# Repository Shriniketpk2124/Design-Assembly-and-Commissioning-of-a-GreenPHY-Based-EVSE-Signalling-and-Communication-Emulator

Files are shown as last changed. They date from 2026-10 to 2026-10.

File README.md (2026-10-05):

# Design, Assembly and Commissioning of a GreenPHY-Based EVSE Signalling and Communication Emulator

> **New here?** Start with [the software quickstart](docs/SOFTWARE_QUICKSTART.md) — two ways to fire up the JoSEV SECC (real hardware, or a two-container software simulation).

This repository documents an engineering prototype for EVSE-side control-pilot
(CP) signalling, HomePlug Green PHY communication and ISO 15118 message
observation with a real electric vehicle.

The project combines a custom mixed-signal PCB, an Arduino Nano, a Raspberry
Pi, a Devolo Green PHY modem and a hardware-adapted EcoG `iso15118` SECC.

> [!CAUTION]
> This is a laboratory communication emulator, not a charger. It has no
> authorized high-voltage DC source, verified insulation-monitoring system,
> pre-charge power stage or energy-transfer path. Never connect an HV/DC source
> or use this project to charge a vehicle.

## Demonstrated scope

The validated setup demonstrated:

- IEC 61851 CP generation and feedback monitoring;
- 1 kHz CP PWM, including the 5% HLC duty cycle;
- EV detection through the CP resistor states;
- EVSE-side SLAC using the `plc-utils` `evse` process;
- IPv6 link-local communication and SDP;
- ISO 15118-2 application-message exchange with external payment and no TLS;
- controlled termination before any physical energy transfer.

The final communication experiment used an explicitly enabled, protocol-only
PreCharge probe. It emulated the protocol status needed to pass CableCheck,
reached `PreChargeReq`, rejected the requested voltage/current command and
latched an external STOP. No DC output was produced.

## Repository layout

| Path | Contents |
| --- | --- |
| `hardware/kicad/PWM_Schematic/` | KiCad schematic, PCB, project-local symbols and footprints, and ERC/DRC reports |
| `hardware/bom/` | Bill of materials exported from the final schematic |
| `software/arduino/` | Arduino Nano CP controller and feedback-monitor firmware |
| `software/raspberry-pi/` | Raspberry Pi console, cockpit, test-day and evidence-collection tools |
| `software/josev-modifications/` | Hardware-controller additions for the EcoG ISO 15118 SECC |
| `software/configuration/` | Public configuration templates without local identifiers or secrets |
| `validation/procedures/` | Bench and real-EV validation procedures |
| `validation/selected-results/` | Sanitized results selected for publication |
| `thesis/` | Publication status only; the thesis report is not distributed here |

Raw packet captures, complete run folders, local environment files, vehicle
identifiers and PLC network keys are intentionally excluded.

## System overview

1. The Arduino generates the CP waveform and publishes comparator feedback over
   a serial connection.
2. The Raspberry Pi console is the sole owner of the Arduino serial connection
   and the two CP-path relay GPIOs.
3. The console writes an atomic state snapshot under `/run/evse-monday`.
4. The modified SECC reads that snapshot instead of controlling serial or GPIO
   hardware from inside the container.
5. The `plc-utils` `evse` process is the sole EVSE-side SLAC owner.
6. The Devolo modem carries HomePlug Green PHY traffic between the PCB coupling
   network and the vehicle.
7. The operations script records packet captures, application logs, controller
   state and checksums for each test attempt.

The word **Monday** remains in several tested script, class and configuration
names. It was the internal name of the final real-EV test workflow; it is not a
separate product or protocol.

## Hardware interface

The final KiCad PCB assigns the four-position vehicle-interface terminal as:

| Terminal | Net |
| --- | --- |
| `J2.1` | `EVSE_CP_OUT` |
| `J2.2` | `EVSE_PP_OUT` |
| `J2.3` | `ISO_GND` |
| `J2.4` | Not connected |

Verify these assignments against the supplied schematic and PCB before making
any physical connection. Wiring changes must be performed with all power
removed.

## Software provenance

The Josev modifications were developed against:

- upstream repository: `https://github.com/EcoG-io/iso15118.git`
- recorded base commit: `76bf85be572d16adbcd009a985d605622c3b7227`

The repository contains the project-specific additions and operational files,
not a claim of ownership over the upstream project. Retain all upstream license
and attribution notices when constructing a working tree.

## Replication order

This project is not a one-command charger build. A new user should proceed in
the following order:

1. Read this README and the safety limits.
2. Open `hardware/kicad/PWM_Schematic/PWM_Schematic.kicad_pro` and inspect the
   schematic, PCB, connector assignments and ERC/DRC reports.
3. Review the BOM and confirm every fitted component and polarity against the
   physical assembly.
4. Compile the Arduino sketch in `software/arduino/evse_cp_feedback_led/` for an
   Arduino Nano. The final sketch was verified with Arduino IDE and used 6102
   bytes of program storage and 448 bytes of global SRAM.
5. Prepare a Raspberry Pi with Docker Compose, Python 3, `tmux`, `tcpdump`,
   `plc-utils` and the required GPIO/serial permissions.
6. Follow the [Raspberry Pi installation and first-start guide](software/raspberry-pi/README.md)
   to check out the recorded upstream `iso15118` revision, prepare the local
   configuration and install the project additions.
7. Copy the public templates from `software/configuration/` to local,
   git-ignored configuration files and replace every `CHANGE_ME` value.
8. Run the hardware-independent tests and the operations-script preflight.
9. Validate State A, State B and 5% HLC feedback using bench loads before a
   vehicle is connected.
10. Only after the bench checks pass, follow the hardware-specific procedure in
    `validation/procedures/REAL_EV_COMMUNICATION_TEST_RUNBOOK.md`.

## Operating modes

`MONDAY_PRECHARGE_PROBE` materially changes the protocol boundary:

| Value | Behaviour |
| --- | --- |
| `0` | Default fail-safe mode. Reports `No_IMD`/`EVSE_NotReady` and requests STOP when CableCheck cannot be truthfully completed. |
| `1` | Test-only protocol probe. Emulates CableCheck readiness to observe entry into PreCharge, but still blocks the requested charging command and requests STOP. |

The probe does not add an IMD, contactor, pre-charge circuit or voltage source.
Do not enable it on a system containing an HV/DC energy path.

## Evidence and privacy

Complete test archives can contain MAC addresses, PLC network keys, EVCC
identifiers, hostnames, operator names and packet payloads. They are private
laboratory evidence and are not suitable for direct publication. Publish only
purpose-selected, sanitized extracts.

## Project status

The repository captures a thesis prototype and its validated laboratory
workflow. It is intended for research, review and reproducibility work by
qualified users. It is not production EVSE firmware and has not been certified
for charging, electrical safety or standards conformance.

The thesis report is withheld until publication permission is confirmed.

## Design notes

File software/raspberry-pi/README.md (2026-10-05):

# Raspberry Pi communication-controller workflow

This directory contains the host-side controller, test-day cockpit and evidence
collection tools used by the GreenPHY EVSE signalling and communication
emulator.

The historical name **Monday** is retained in filenames and runtime paths
because those names belong to the tested integration. It refers to the final
real-EV workflow, not to a protocol or separate software product.

> [!CAUTION]
> The software is for a communication-only laboratory rig. It must not control
> an HV/DC source or be treated as a production EVSE controller.

## Responsibilities

| Component | Responsibility |
| --- | --- |
| `evse_monday_console.py` | Sole owner of the Arduino serial connection and CP-path relay GPIOs |
| `monday_status.py` | Decodes and displays the current host state snapshot |
| `monday_ops.sh` | Preflight, service startup, cockpit, SLAC, capture, diagnosis, STOP, evidence collection and shutdown |
| `install_monday.sh` | Installs the project-specific files into a prepared upstream working tree |
| `verify_monday.sh` | Compatibility wrapper that invokes the final `monday_ops.sh preflight` checks |
| `tests/` | Hardware-independent parser, state and fail-safe tests |

The modified SECC does not open the Arduino serial port or directly control the
Pi GPIOs. It exchanges small JSON state/command files with the host under
`/run/evse-monday`.

## Installation and first startup

These instructions create a separate EcoG `iso15118` checkout and install the
project additions into it. They do not turn the prototype into a charger.
Keep the vehicle disconnected and keep every HV/DC source absent during the
installation and software checks.

The validated host was a Raspberry Pi 3B running a Debian-based Raspberry Pi
OS. The tested hardware names are fixed in the operational scripts:

- Green PHY interface: `eth0`;
- Arduino serial device: `/dev/ttyUSB0`;
- relay GPIOs: GPIO17 and GPIO27.

If the target uses different names or GPIOs, update and revalidate the scripts
before connecting a vehicle.

### 1. Install and verify host tools

On a Debian-based Raspberry Pi OS, install the ordinary command-line
dependencies with:

```bash
sudo apt update
sudo apt install -y \
  git make openssl python3 python3-serial \
  tmux tcpdump iproute2 util-linux coreutils psmisc default-jre
```

Install Docker Engine with the Docker Compose plugin using the instructions for
the installed Raspberry Pi OS release. Install Qualcomm Atheros `plc-utils`
and ensure that the Raspberry Pi `pinctrl` command is available. Package names
for Docker, `plc-utils` and `pinctrl` differ between OS releases, so verify the
result directly:

```bash
python3 --version
docker --version
sudo docker compose version
command -v tmux tcpdump ip ss script stdbuf sha256sum
command -v evse plctool plcstat pinctrl
```

Do not continue until every command returns successfully.

### 2. Clone this project and the recorded upstream revision

The project-specific Josev files were developed against EcoG `iso15118` commit
`76bf85be572d16adbcd009a985d605622c3b7227`. Use a separate checkout so another
simulation or development tree is not overwritten:

```bash
export PROJECT_CHECKOUT="$HOME/greenphy-evse-emulator"
export MONDAY_HOME="$HOME/thesis-monday-real-ev"
export MONDAY_REPO="$MONDAY_HOME/iso15118-real-ev"

git clone \
  https://github.com/Shriniketpk2124/Design-Assembly-and-Commissioning-of-a-GreenPHY-Based-EVSE-Signalling-and-Communication-Emulator.git \
  "$PROJECT_CHECKOUT"

mkdir -p "$MONDAY_HOME"
git clone https://github.com/EcoG-io/iso15118.git "$MONDAY_REPO"
git -C "$MONDAY_REPO" checkout --detach \
  76bf85be572d16adbcd009a985d605622c3b7227
git -C "$MONDAY_REPO" rev-parse HEAD
```

The final command must print the recorded commit exactly.

### 3. Build the SECC dependency image

The runtime Compose file expects an image named `iso15118-secc:latest`. Build
that image from the recorded upstream checkout:

```bash
cd "$MONDAY_REPO"
make generate_v2_certs
cp template.Dockerfile iso15118/secc/Dockerfile
sudo docker build \
  --tag iso15118-secc:latest \
  --file iso15118/secc/Dockerfile \
  .
sudo docker pull redis:6.2.6-alpine
```

Confirm both images before continuing:

```bash
sudo docker image inspect iso15118-secc:latest >/dev/null
sudo docker image inspect redis:6.2.6-alpine >/dev/null
```

The image provides the upstream Python dependencies and Java EXI runtime. The
project's Compose file later mounts the installed `iso15118` source tree into
the container.

### 4. Create the three private configuration files

Create local copies from the public templates:

```bash
cp "$PROJECT_CHECKOUT/software/configuration/.env.example" \
  "$PROJECT_CHECKOUT/software/configuration/.env.monday-real-ev"
cp "$PROJECT_CHECKOUT/software/configuration/monday-ops.env.example" \
  "$PROJECT_CHECKOUT/software/configuration/monday-ops.env"
cp "$PROJECT_CHECKOUT/software/configuration/slac/evse-monday.example.ini" \
  "$PROJECT_CHECKOUT/software/configuration/slac/evse-monday.ini"

chmod 600 \
  "$PROJECT_CHECKOUT/software/configuration/.env.monday-real-ev" \
  "$PROJECT_CHECKOUT/software/configuration/monday-ops.env" \
  "$PROJECT_CHECKOUT/software/configuration/slac/evse-monday.ini"
```

Edit all three files and replace every `CHANGE_ME`. Use `eth0` as
`NETWORK_INTERFACE` for the published operational scripts. The SLAC profile
must contain the local, authorized PLC parameters for the adapter and test
environment; do not copy identifiers or keys from published captures.

After editing the SLAC profile, calculate its checksum:

```bash
sha256sum \
  "$PROJECT_CHECKOUT/software/configuration/slac/evse-monday.ini"
```

Copy the resulting 64-character value into `MONDAY_PROFILE_SHA256` in
`monday-ops.env`. Also enter the local QCA7000/Devolo adapter address as
`DEVOLO_MAC`.

Keep `MONDAY_PRECHARGE_PROBE=0` for the default fail-safe installation. Confirm
that no placeholders remain:

```bash
grep -RInE '=[[:space:]]*CHANGE_ME[[:space:]]*$' \
  "$PROJECT_CHECKOUT/software/configuration/.env.monday-real-ev" \
  "$PROJECT_CHECKOUT/software/configuration/monday-ops.env" \
  "$PROJECT_CHECKOUT/software/configuration/slac/evse-monday.ini"
```

The final command must produce no output. These local files are ignored by
Git. Never commit adapter addresses, PLC network material or other identifiers.

### 5. Install the project additions

Tell the installer where the private files and upstream checkout are located:

```bash
export MONDAY_ENV_FILE="$PROJECT_CHECKOUT/software/configuration/.env.monday-real-ev"
export MONDAY_OPS_ENV_FILE="$PROJECT_CHECKOUT/software/configuration/monday-ops.env"
export MONDAY_SLAC_PROFILE="$PROJECT_CHECKOUT/software/configuration/slac/evse-monday.ini"

"$PROJECT_CHECKOUT/software/raspberry-pi/install_monday.sh"
```

The installer:

- verifies the recorded upstream commit;
- backs up previously installed project files;
- installs the Josev controller additions and Compose file;
- installs the host console, status and operations tools;
- installs the three private configuration files with mode `0600`;
- compiles the Python files and runs the included hardware-independent tests.

It does not install OS packages, build the Docker image, flash the Arduino or
perform any physical safety check.

### 6. Load the operations configuration and run preflight

Connect the Arduino and Devolo adapter, but keep the vehicle disconnected.
Confirm that `eth0` and `/dev/ttyUSB0` are the intended devices:

```bash
ip -br link
ls -l /dev/ttyUSB0
```

Load the local operations settings and run the read-only preflight:

```bash
set -a
. "$MONDAY_HOME/monday-ops.env"
set +a

"$MONDAY_HOME/verify_monday.sh"
```

The preflight checks the required files and commands, Ethernet carrier, IPv6
link-local address, Arduino device, local QCA7000 response, SLAC-profile hash,
Compose configuration, Docker images, running processes and required ports.
Do not connect a vehicle if any item fails.

### 7. Start and stop the software

After the hardware-independent tests, preflight and bench CP checks have
passed, start the integrated cockpit with:

```bash
"$MONDAY_HOME/monday_ops.sh" test-day
```

At the `bench>` prompt, establish the safe initial state one command at a
time:

```text
reset
remote on
a
status
```

Do not enter `hlc` until the approved bench procedure or real-vehicle runbook
requires it and stable State B has been confirmed. If the SSH connection is
lost, reconnect and run:

```bash
"$MONDAY_HOME/monday_ops.sh" cockpit
```

For a normal shutdown, use the guarded cockpit menu or run from a separate SSH
session:

```bash
set -a
. "$MONDAY_HOME/monday-ops.env"
set +a
"$MONDAY_HOME/monday_ops.sh" shutdown
```

The evidence path can then be displayed with:

```bash
"$MONDAY_HOME/monday_ops.sh" paths
```

The run directory is private evidence and can contain vehicle and network
identifiers. Do not commit it.

## PreCharge-probe setting

Keep this disabled for the default fail-safe configuration:

```text
MONDAY_PRECHARGE_PROBE=0
```

With the value `0`, the controller reports `No_IMD` and `EVSE_NotReady` and
requests host STOP when the stack reaches a boundary that cannot be truthfully
completed by the rig.

The value `1` enables the thesis experiment's test-only protocol probe. After
CableCheck begins, the software emulates the protocol status needed to observe
entry into PreCharge. It does not close a physical DC contactor, perform an
isolation measurement or generate DC voltage. A received voltage/current target
is blocked and causes a latched host STOP.

Never enable the probe on hardware containing an HV/DC source or energy path.

## Hardware-independent checks

The installer compiles the deployed Python files and runs the three included
test programs. They verify that:

- state snapshots become unusable when stale or malformed;
- unsupported comparator combinations decode to `UNKNOWN`;
- the STOP command is latched;
- charging commands cannot silently pass through the controller;
- only one process owns the serial/GPIO interface;
- only one EVSE-side SLAC process is active.

After those tests pass, load `monday-ops.env` and run:

```bash
"$MONDAY_HOME/monday_ops.sh" preflight
```

Do not connect a vehicle if any preflight item fails.

## Final operating workflow

The final integrated workflow uses `monday_ops.sh`; the older manual sequence of
separate terminals, a separately started packet capture and unresolved SLAC
ownership is obsolete.

Start the environment with:

```bash
"$MONDAY_HOME/monday_ops.sh" test-day
```

The command performs the preflight, creates a timestamped run directory,
starts packet capture, Redis and the SECC, waits for UDP 15118 and opens a
four-pane `tmux` cockpit:

| Pane | Function |
| --- | --- |
| Large left | Interactive console and sole serial/GPIO owner |
| Upper right | Decoded CP state and freshness monitor |
| Middle right | Sole `plc-utils` EVSE SLAC owner |
| Lower right | Live SECC application log |

Reconnect to an existing cockpit with:

```bash
"$MONDAY_HOME/monday_ops.sh" cockpit
```

Use the operator menu for status, diagnosis, snapshots, fail-safe STOP and
confirmed shutdown. CP-changing commands remain deliberate console actions.

## CP mapping used by the controller

A snapshot is accepted only when it is fresh, stable, fault-free and internally
consistent. With the CP-path relays commanded on, heartbeat supervision must
also be active.

| Arduino output | `FB_PAIR` | Decoded state |
| --- | ---: | ---: |
| Relays commanded off | any | A1 |
| Positive DC | `00` | A1 |
| Positive DC | `10` | B1 |
| Positive DC | `01` | C1 |
| 5% HLC PWM | `00` | A2 |
| 5% HLC PWM | `10` | B2 |
| 5% HLC PWM | `11` | C2 |

Every other combination is `UNKNOWN`.

## SLAC ownership

The final workflow uses exactly one `plc-utils` `evse` process as the EVSE-side
SLAC owner. `monday_ops.sh test-day` starts it in the cockpit after the SECC is
available. Do not start `pyslac`, a second `evse` process or another SLAC owner
on the same interface.

Before the EV is connected, the normal listener output includes a successful
`CM_SET_KEY` result followed by the unoccupied/listening state. Ethernet carrier
or an IPv6 link-local address alone does not prove successful SLAC.

## Safe shutdown and evidence

Use the console to request session stop, then use the guarded operations menu or
run:

```bash
"$MONDAY_HOME/monday_ops.sh" shutdown
```

The workflow verifies or requests the safe CP state, stops packet capture,
collects logs and final state, stops services and creates checksums.

Complete run directories are private by default. They may contain EVCC IDs,
MAC addresses, PLC network keys, host details and packet payloads. Publish only
sanitized, purpose-selected results.

## Real-vehicle procedure

Do not derive a vehicle test from this README alone. Follow the
[real-EV communication test runbook](../../validation/procedures/REAL_EV_COMMUNICATION_TEST_RUNBOOK.md)
after the bench checks and preflight have passed.

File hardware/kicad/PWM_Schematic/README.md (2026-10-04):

\# PWM and Control-Pilot PCB

This directory contains the KiCad source files for the mixed-signal PCB used by

the Green PHY EVSE signalling and communication emulator.

\## Requirements

\- KiCad 10

\- Standard KiCad symbol libraries

\- Standard KiCad footprint libraries

\- Standard KiCad 3D-model package, if 3D rendering is required

\## Opening the project

Open:

`PWM\_Schematic.kicad\_pro`

The custom symbol and footprint libraries required by the project are included

locally in the `symbols/` and `footprints/` directories. The corresponding

`sym-lib-table` and `fp-lib-table` files use `${KIPRJMOD}` paths, so the project

does not depend on machine-specific directories.

\## Included source files

\- `PWM\_Schematic.kicad\_pro` — KiCad project settings

\- `PWM\_Schematic.kicad\_sch` — schematic

\- `PWM\_Schematic.kicad\_pcb` — PCB layout

\- `PWM\_Schematic.kicad\_dru` — custom design rules

\- `symbols/` — project-local custom symbols

\- `footprints/` — project-local custom footprints

\- `reports/` — final ERC and DRC reports

\## Verification status

Final verification performed on 2026-10-04:

\- ERC errors: 0

\- ERC warnings: 0

\- DRC violations: 0

\- Unconnected pads: 0

\- Footprint errors: 0

The corresponding reports are stored in `reports/`.

\## 3D models

Standard components use the official KiCad 10 3D-model library where available.

Nonportable or incorrect custom 3D-model references were removed. Missing custom

3D models do not affect schematic connectivity, PCB routing, fabrication output

or design-rule verification.

\## Fabrication outputs

Historical Gerber and Aisler exports are not included because they predate the

final DRC-clean source revision. Fabrication outputs should be regenerated from

the checked PCB source when required.

\## Scope and safety

This PCB is a research prototype for control-pilot signalling, proximity-pilot

interfacing and communication-layer experimentation. It is not a certified EVSE

power stage and must not be treated as authorization for high-voltage or energy

transfer.

\## Third-party library data

Some project-local symbol and footprint definitions originated from manufacturer

or electronic-library-loader data and were adapted for this project. Applicable

redistribution terms must be reviewed before making the repository public.

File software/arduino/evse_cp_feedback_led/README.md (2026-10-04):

\# Arduino Control-Pilot Controller

This Arduino Nano firmware generates the control-pilot command waveform and

monitors two digital comparator-feedback channels for the Green PHY EVSE

signalling and communication emulator.

\## Target

\- Arduino Nano

\- ATmega328P

\- 16 MHz

\- Arduino AVR core

\- No additional Arduino libraries required

\## Build verification

Verified with Arduino IDE on 2026-10-04.

\- Program storage: 6,102 of 30,720 bytes (19%)

\- Global variables: 448 of 2,048 bytes (21%)

\- Remaining dynamic memory: 1,600 bytes

\## Pin assignment

| Nano pin | Function |

|---|---|

| D9 | Timer1 control-pilot output through U3 |

| D2 | Comparator feedback input |

| D3 | Comparator feedback input |

| D4 | D2 diagnostic indication |

| D5 | D3 diagnostic indication |

| D6 | Feedback-settling diagnostic indication |

D2 and D3 require the external pull-ups provided by the validated hardware and

are always configured as inputs.

\## Serial interface

\- Baud rate: 115200

\- Line ending: newline

\- Maximum command length: 80 characters

Supported commands include:

\- `HELP`

\- `STATUS`

\- `A`

\- `HLC`

\- `PWM <duty>`

\- `SESSION START`

\- `SESSION STOP`

\- `DISABLE`

\- `FAULT <text>`

\- `RESET`

\- `REMOTE ON`

\- `REMOTE OFF`

\- `HB`

\- `PING <text>`

\## Operational behavior

U3 inverts the Arduino D9 output. A 5% positive control-pilot duty therefore

requires D9 to remain high for approximately 95% of the period.

Remote supervision uses a three-second timeout. Any received nonempty command

refreshes the host-activity timestamp, including `HB`.

\## Safety scope

The firmware does not control the Raspberry Pi relay outputs and does not

measure contactor feedback. `CONTACTORS=OFF` is retained only as a serial

protocol status field.

Comparator bit pairs and diagnostic LEDs are not proof of a valid control-pilot

voltage, connected vehicle or permission to transfer energy.

This firmware belongs to a communication-only research prototype and must not

be used as a certified EVSE controller or high-voltage safety function.

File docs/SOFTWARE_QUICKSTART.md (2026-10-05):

# Software Quickstart — firing up the JoSEV SECC

This guide shows the two ways to run the ISO 15118-2 communication software (the
hardware-adapted EcoG **JoSEV** SECC). It only covers JoSEV; pyPLC / DIN SPEC
70121 is out of scope here.

Pick the mode that matches what you have:

| Mode | You have | What runs | What it proves |
| --- | --- | --- | --- |
| **A — Hardware in the loop** | The custom board, Arduino Nano, Devolo Green PHY modem and a Raspberry Pi | The hardware-adapted SECC (`monday_main`) plus the Pi console, the `plc-utils` SLAC owner and a live packet capture | The full CP + Green PHY + ISO 15118-2 path with a real vehicle, up to the first `PreChargeReq` |
| **B — Software-only simulation** | Any Linux host (or Windows with WSL2) and Docker | Two upstream JoSEV containers, an **SECC** and an **EVCC**, talking over Docker's internal IPv6 network | The ISO 15118-2 DC message flow end to end, in software, with no board and no modem |

> [!CAUTION]
> This is a communication-only laboratory rig, not a charger. It has no HV/DC
> source, insulation monitor, pre-charge stage or energy path. In Mode A you are
> driving a real vehicle's Control Pilot line, so finish the bench checks first
> and **never** enable the PreCharge probe (`MONDAY_PRECHARGE_PROBE=1`) on any
> system that contains an HV/DC path.

---

## Mode A — Hardware in the loop

### How the pieces talk

```mermaid
flowchart LR
    ARD["Arduino Nano<br/>CP generate + comparator feedback"] -- USB serial --> CON["Pi console<br/>evse_monday_console.py<br/>(sole serial + GPIO owner)"]
    CON -- "GPIO17 / GPIO27" --> RLY["CP-path relays K1/K2"]
    CON -- "atomic JSON snapshot" --> ST["/run/evse-monday/state.json"]
    ST -- "read-only" --> SECC["JoSEV SECC container<br/>iso15118.secc.monday_main"]
    SLAC["plc-utils evse<br/>(sole SLAC owner)"] --- DEV["Devolo Green PHY modem"]
    SECC --- DEV
    DEV -- "CP conductor" --> EV["Vehicle"]
```

The SECC never opens the serial port or GPIOs. It only reads the state snapshot
the console writes, so there is exactly one owner of the hardware.

### One-time setup

1. **Prepare the Pi.** Raspberry Pi OS (Debian-based), Python 3, Docker with the
   Compose plugin, and `tmux tcpdump ip ss script stdbuf sha256sum pinctrl`.
2. **Build `open-plc-utils` from source** (`qca/open-plc-utils`) so you have
   `evse`, `plctool` and `plcstat` on the path. There is no stock apt package.
3. **Flash the Arduino** sketch in `software/arduino/evse_cp_feedback_led/` onto
   an Arduino Nano.
4. **Get the upstream SECC.** Clone the EcoG stack at the recorded compatible
   revision, in a checkout of its own:
   ```bash
   git clone https://github.com/EcoG-io/iso15118.git
   cd iso15118
   git checkout 76bf85be572d16adbcd009a985d605622c3b7227
   ```
5. **Apply the project files** from `software/josev-modifications/` into that
   tree with `software/raspberry-pi/install_monday.sh` (review its paths first;
   the validated Pi directory was `~/thesis-monday-real-ev`).
6. **Build the image** `iso15118-secc:latest` from that tree (the compose file
   also uses `redis:6.2.6-alpine`).
7. **Make your local config** from the templates, and fill every `CHANGE_ME`:
   | Template (committed) | Local file (git-ignored) |
   | --- | --- |
   | `software/configuration/.env.example` | `.env.monday-real-ev` |
   | `software/configuration/monday-ops.env.example` | `monday-ops.env` |
   | `software/configuration/slac/evse-monday.example.ini` | `slac/evse-monday.ini` |

   Keep `MONDAY_PRECHARGE_PROBE=0`. Put your Devolo adapter MAC, the SLAC profile
   and its SHA-256, and your PLC network key only in these local files. Never
   commit them.

### Fire it up (each test day)

```bash
# load the ops environment into this shell
set -a; . /path/to/monday-ops.env; set +a

# hardware-independent tests, then readiness checks with the EV DISCONNECTED
python -m pytest software/raspberry-pi/tests
/path/to/monday_ops.sh preflight

# bench-verify State A, State B and the 5% HLC feedback against known loads
# (use the console; see software/raspberry-pi/README.md)

# start everything and open the cockpit
/path/to/monday_ops.sh test-day
```

`test-day` runs the preflight, creates a timestamped run folder, starts the
packet capture, Redis and the SECC, waits for UDP 15118, and opens a four-pane
`tmux` cockpit:

| Pane | Function |
| --- | --- |
| Large left | Console — sole serial/GPIO owner (you drive CP here) |
| Upper right | Decoded CP state + freshness |
| Middle right | `plc-utils` SLAC owner |
| Lower right | Live SECC log |

Reconnect later with `monday_ops.sh cockpit`. When finished, request a session
stop from the console, then:

```bash
/path/to/monday_ops.sh shutdown   # safe CP state, stop capture, collect logs, checksums
```

Only after the bench checks and preflight pass should you follow
`validation/procedures/REAL_EV_COMMUNICATION_TEST_RUNBOOK.md` for the real
vehicle.

---

## Mode B — Software-only simulation (two JoSEV containers)

No board, no modem, no `plc-utils`, no Arduino. This runs the **upstream EcoG
JoSEV** dev stack, where an EVCC container and an SECC container complete a full
ISO 15118-2 DC session over Docker's internal network. It does **not** use this
repo's hardware SECC (`monday_main`), which expects the live state snapshot from
the Pi console.

On Windows, do this inside WSL2 (Ubuntu). On Linux, run it directly.

```bash
# 1. get the upstream stack
git clone https://github.com/EcoG-io/iso15118.git
cd iso15118

# 2. if the image build fails on an end-of-life base, move it to bookworm
grep -rl "buster" *.Dockerfile Dockerfile* docker/ 2>/dev/null \
  | xargs -r sed -i 's/python:3.10.0-buster/python:3.10-bookworm/g'

# 3. select DC charging with EIM (thesis scope)
sed -i 's/evcc_config_eim_ac.json/evcc_config_eim_dc.json/g' .env.dev.docker

# 4. build the SECC and EVCC images (first build takes a few minutes)
make build

# 5. start Redis + SECC + EVCC, and keep a log
make dev 2>&1 | tee josev_dc_session_log.txt

# stop with Ctrl+C
```

The EVCC waits a few seconds for the SECC, then runs SDP discovery and the V2G
message exchange. TLS stays off and payment is external identification (EIM), so
the flow mirrors the thesis session: `SDP → supportedAppProtocol → SessionSetup
→ ServiceDiscovery → PaymentServiceSelection → Authorization →
ChargeParameterDiscovery → CableCheck → PreCharge → PowerDelivery →
CurrentDemand → PowerDelivery → WeldingDetection → SessionStop`. The simulated
EVCC uses the stack's built-in placeholder battery values, which differ from the
real-vehicle capture in the thesis.

---

## Command reference (Mode A, `monday_ops.sh`)

| Command | Purpose |
| --- | --- |
| `preflight` | Read-only readiness checks; needs a clean stopped session |
| `start` | Run folder + packet capture + Redis + SECC |
| `test-day` | `start`, then open the four-pane cockpit |
| `cockpit` | Open or reconnect the cockpit |
| `console` | Interactive Arduino/GPIO console (sole owner) |
| `slac` | The single `plc-utils` EVSE SLAC owner |
| `monitor` / `secc-logs` | Follow decoded CP state / SECC log |
| `status` / `diagnose` | Processes, sockets, CP snapshot, PLC table / layer-by-layer check |
| `stop` | Latched fail-safe STOP, verify relays OFF |
| `collect` / `shutdown` | Gather evidence / safe state + stop all services |

No `monday_ops.sh` command ever produces A, HLC or PWM on the Control Pilot.
Those are deliberate console actions, taken only after the physical setup and CP
state are checked.

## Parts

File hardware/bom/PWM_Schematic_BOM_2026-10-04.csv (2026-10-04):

Reference | Value | Footprint | Qty | Description | Datasheet | #
A1 | Arduino_Nano_v3.x | Module:Arduino_Nano | 1 | Arduino Nano v3.x | http://www.mouser.com/pdfdocs/Gravitech_Arduino_Nano3_0.pdf | 1
C1,C2,C11,C14,C15 | 100nF | Capacitor_THT:C_Disc_D5.0mm_W2.5mm_P2.50mm | 5 | Unpolarized capacitor |  | 2
C3,C4 | 10uF | Capacitor_THT:CP_Radial_D5.0mm_P2.00mm | 2 | Polarized capacitor |  | 3
C5 | 0.1uF | Capacitor_THT:C_Disc_D5.0mm_W2.5mm_P2.50mm | 1 | Unpolarized capacitor |  | 4
C6 | 220nF | PWM_Schematic:C_Universal_P2.54_L5.5_W3.5 | 1 | Unpolarized capacitor |  | 5
C7 | 10nF | Capacitor_THT:C_Disc_D5.0mm_W2.5mm_P2.50mm | 1 | Unpolarized capacitor |  | 6
C8 | 680u | Capacitor_THT:CP_Radial_D12.5mm_P5.00mm | 1 | Polarized capacitor |  | 7
C9 | 330u | Capacitor_THT:CP_Radial_D10.0mm_P5.00mm | 1 | Polarized capacitor |  | 8
C10 | 1nF | Capacitor_THT:C_Disc_D5.0mm_W2.5mm_P2.50mm | 1 | Unpolarized capacitor |  | 9
C12,C13 | 2.7nF / 2kV | Capacitor_THT:C_Rect_L18.0mm_W5.0mm_P15.00mm_FKS3_FKP3 | 2 | 2.7 nF, 2 kV, ±5%, polypropylene film capacitor, THT, 15 mm pitch |  | 10
C16,C17 | 100nF | Capacitor_SMD:C_0805_2012Metric | 2 | Unpolarized capacitor |  | 11
D1,D2 | 1N4001 | Diode_THT:D_DO-41_SOD81_P7.62mm_Horizontal | 2 | Diode |  | 12
D3,D4,D8,D9,D10 | LED | LED_THT:LED_D5.0mm | 5 | Light emitting diode |  | 13
D5 | 1N4148 | Diode_THT:D_DO-35_SOD27_P7.62mm_Horizontal | 1 | Diode |  | 14
D6 | SB540 | Diode_THT:D_DO-201AD_P15.24mm_Horizontal | 1 | Diode |  | 15
D7 | 1N5817 | Diode_THT:D_DO-41_SOD81_P7.62mm_Horizontal | 1 | Schottky diode |  | 16
DZ_1 | 5.1V | Diode_THT:D_DO-35_SOD27_P7.62mm_Horizontal | 1 | Zener diode |  | 17
D_CP1 | SMAJ14CA | Diode_SMD:D_SMA | 1 | 400W bidirectional Transient Voltage Suppressor, 14.0Vr, SMA(DO-214AC) | https://www.littelfuse.com/media?itemid=75e32973-b177-4ee3-a0ff-cedaf1abdb93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 | 18
D_OV1,D_OV2 | 1.5KE15CA | Diode_THT:D_DO-201AD_P15.24mm_Horizontal | 2 | Bidirectional transient-voltage-suppression diode |  | 19
D_RP1,D_RP2 | SB540 | Diode_THT:D_DO-201AD_P15.24mm_Horizontal | 2 | Schottky diode |  | 20
IC1 | LM2596T-5.0_NOPB | PWM_Schematic_Custom:TO170P470X1028X2117-5P | 1 | SIMPLE SWITCHER&#174; 4.5V to 40V, 3A Low Component Count Step-Down Regulator | http://www.ti.com/lit/gpn/lm2596 | 21
IC2 | LM393AP | PWM_Schematic_Custom:LM393_DIP8_AISLER_0p30mm_Annular | 1 | LM393P, Dual Comparator Open Collector 1.3us 12 V, 15 V, 18 V, 24 V, 28 V, 3 V, 5 V, 9 V 8-Pin PDIP | http://www.ti.com/lit/ds/symlink/lm393.pdf | 22
IC3 | TPS26600PWPR | Package_SO:HTSSOP-16-1EP_4.4x5mm_P0.65mm_EP3x3mm | 1 | 60V 2A Industrial eFuse With Integrated Reverse-Input Polarity Protection | http://www.ti.com/lit/gpn/tps2660 | 23
J1 | DEVOLO_PLC - MKDS 1,5/2-5,08 - 1715721 | PWM_Schematic:TerminalBlock_Universal_1x02_P5.08_Phoenix_Molex | 1 | Generic connector, single row, 01x02, script generated (kicad-library-utils/schlib/autogen/connector/) |  | 24
J2 | Conn_01x04 | TerminalBlock_Phoenix:TerminalBlock_Phoenix_MPT-0,5-4-2.54_1x04_P2.54mm_Horizontal | 1 | Generic connector, single row, 01x04, script generated (kicad-library-utils/schlib/autogen/connector/) |  | 25
J3 | USB-PD Trigger-(20V) | Connector_PinSocket_2.54mm:PinSocket_1x02_P2.54mm_Vertical | 1 | Generic connector, single row, 01x02, script generated (kicad-library-utils/schlib/autogen/connector/) |  | 26
JP1 | PI_PWR_LINK | Connector_PinHeader_2.54mm:PinHeader_1x02_P2.54mm_Vertical | 1 | Jumper, 2-pole, open |  | 27
JP2 | PLC_COUPLING_BYPASS | Connector_PinHeader_2.54mm:PinHeader_1x02_P2.54mm_Vertical | 1 | Jumper, 2-pole, open |  | 28
JP3 | CP_LPF_BYPASS | Connector_PinHeader_2.54mm:PinHeader_1x02_P2.54mm_Vertical | 1 | Jumper, 2-pole, open |  | 29
JP4 | UART_PI_TX_ENABLE | Connector_PinHeader_2.54mm:PinHeader_1x02_P2.54mm_Vertical | 1 | Jumper, 2-pole, open |  | 30
JP5 | UART_ARD_TX_ENABLE | Connector_PinHeader_2.54mm:PinHeader_1x02_P2.54mm_Vertical | 1 | Jumper, 2-pole, open |  | 31
K1 | HF3FA-005-Z | PWM_Schematic_Custom:Relay_SPDT_SANYOU_SRD_Series_Form_C Modified_1 | 1 |  | http://www.sanyourelay.ca/public/products/pdf/SRD.pdf | 32
K2 | HF3FA-005-Z | PWM_Schematic_Custom:Relay_SPDT_SANYOU_SRD_Series_Form_C_Modified | 1 |  | http://www.sanyourelay.ca/public/products/pdf/SRD.pdf | 33
L2 | 2100LL-470-H-RC | PWM_Schematic_Custom:L2_AISLER_0p30mm_Annular | 1 | Inductor |  | 34
L3 | 220uH | PWM_Schematic:L_Wurth_7447020_P7.00mm_1 | 1 | Inductor |  | 35
Q1,Q2 | BC337-40 | Package_TO_SOT_THT:TO-92_Inline_Wide | 2 | 0.8A Ic, 45V Vce, NPN Transistor, TO-92 | https://diotec.com/tl_files/diotec/files/pdf/datasheets/bc337.pdf | 36
Q3 | VO4661 | PWM_Schematic_Custom:VO4661_DIP8_AISLER_0p30mm_Annular | 1 | Logic Output Optoisolator 10MBd Open Drain 5300Vrms 2 Channel 15kV/s CMTI 8-DIP | https://www.vishay.com/docs/80412/vo2630_vo2631_vo4661.pdf | 37
R1,R2,R41 | 1.8k | Resistor_THT:R_Axial_DIN0207_L6.3mm_D2.5mm_P7.62mm_Horizontal | 3 | Resistor |  | 38
R3,R11,R31,R40 | 1k | Resistor_THT:R_Axial_DIN0207_L6.3mm_D2.5mm_P7.62mm_Horizontal | 4 | Resistor |  | 39
R4,R5,R9 | 1k | Resistor_THT:R_Axial_DIN0207_L6.3mm_D2.5mm_P7.62mm_Horizontal | 3 |  |  | 40
R6 | 4.7k | Resistor_THT:R_Axial_DIN0207_L6.3mm_D2.5mm_P7.62mm_Horizontal | 1 |  |  | 41
R7 | 22k | Resistor_THT:R_Axial_DIN0207_L6.3mm_D2.5mm_P7.62mm_Horizontal | 1 |  |  | 42
R8 | 47k | Resistor_THT:R_Axial_DIN0207_L6.3mm_D2.5mm_P7.62mm_Horizontal | 1 |  |  | 43
R10 | 1.5k | Resistor_THT:R_Axial_DIN0207_L6.3mm_D2.5mm_P7.62mm_Horizontal | 1 |  |  | 44
R12,R13,R19,R20,R30 | 330 | Resistor_THT:R_Axial_DIN0207_L6.3mm_D2.5mm_P7.62mm_Horizontal | 5 | Resistor |  | 45
R14 | 1Meg | Resistor_THT:R_Axial_DIN0207_L6.3mm_D2.5mm_P7.62mm_Horizontal | 1 | Resistor |  | 46
R15,R36 | 13k | Resistor_THT:R_Axial_DIN0207_L6.3mm_D2.5mm_P7.62mm_Horizontal | 2 | Resistor |  | 47
R16,R32 | 10k | Resistor_THT:R_Axial_DIN0207_L6.3mm_D2.5mm_P7.62mm_Horizontal | 2 | Resistor |  | 48
R17 | 15k | Resistor_THT:R_Axial_DIN0207_L6.3mm_D2.5mm_P7.62mm_Horizontal | 1 | Resistor |  | 49
R18 | 6.04k | Resistor_THT:R_Axial_DIN0207_L6.3mm_D2.5mm_P7.62mm_Horizontal | 1 | Resistor |  | 50
R21 | 5.6k | Resistor_THT:R_Axial_DIN0207_L6.3mm_D2.5mm_P7.62mm_Horizontal | 1 | Resistor |  | 51
R22,R23,R33,R37,R38 | 47k | Resistor_THT:R_Axial_DIN0207_L6.3mm_D2.5mm_P7.62mm_Horizontal | 5 | Resistor |  | 52
R24 | 560k | Resistor_THT:R_Axial_DIN0207_L6.3mm_D2.5mm_P7.62mm_Horizontal | 1 | Resistor |  | 53
R25 | 620k | Resistor_THT:R_Axial_DIN0207_L6.3mm_D2.5mm_P7.62mm_Horizontal | 1 | Resistor |  | 54
R26,R27 | 1.5k | Resistor_THT:R_Axial_DIN0207_L6.3mm_D2.5mm_P7.62mm_Horizontal | 2 | Resistor |  | 55
R28,R29,R42 | 3.3k | Resistor_THT:R_Axial_DIN0207_L6.3mm_D2.5mm_P7.62mm_Horizontal | 3 | Resistor |  | 56
R34,R35 | 100k | Resistor_THT:R_Axial_DIN0207_L6.3mm_D2.5mm_P7.62mm_Horizontal | 2 | Resistor |  | 57
R39 | 220 | Resistor_THT:R_Axial_DIN0207_L6.3mm_D2.5mm_P7.62mm_Horizontal | 1 | Resistor |  | 58
R43 | 100R | Resistor_THT:R_Axial_DIN0207_L6.3mm_D2.5mm_P7.62mm_Horizontal | 1 | Resistor |  | 59
TP1 | 5V_RAW | TestPoint:TestPoint_THTPad_D2.0mm_Drill1.0mm | 1 | test point |  | 60
TP2 | 5V_PROTECTED | TestPoint:TestPoint_THTPad_D2.0mm_Drill1.0mm | 1 | test point |  | 61
U1 | OPA2172ID | TLV2172IDR_SOIC8:D8_TEX | 1 |  | https://www.ti.com/lit/gpn/tlv2172 | 62
U2 | TMR-2422 | Converter_DCDC:Converter_DCDC_TRACO_TEC2-12xxWI_24xxWI_48xxWI_THT | 1 | 2 Watt DC/DC converter, industrial, 2:1 input, regulated, 1600 VDC I/O-isolation, encapsulated, SIP-8 | https://tracopower.com/tmr2-datasheet/ | 63
U3 | VO2611 | Package_DIP:DIP-8_W7.62mm | 1 | Single High Speed LSTTL/TTL Compatible Optocoupler with enable, dV/dt 1000/us, VCM 10, max 7V VCC, DIP-8 | https://www.vishay.com/docs/84732/6n137_vo2601_vo2611.pdf | 64
U_RPI1 | Raspberry_Pi_4 | Connector_PinSocket_2.54mm:PinSocket_2x20_P2.54mm_Vertical | 1 | expansion header for Raspberry Pi 2 & 3 | https://www.raspberrypi.org/documentation/hardware/raspberrypi/schematics/rpi_SCH_3bplus_1p0_reduced.pdf | 65

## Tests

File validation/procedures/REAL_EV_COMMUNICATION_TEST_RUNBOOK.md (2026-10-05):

# Real-EV communication test runbook

This is the validated hardware-specific procedure for the GreenPHY EVSE
signalling and communication emulator. The tested scripts retain the internal
name **Monday**.

> [!CAUTION]
> This procedure authorizes CP, PLC, SLAC and ISO 15118 communication only.
> It does not authorize an HV/DC source, physical pre-charge stage, insulation
> monitor, DC output contactor or energy transfer. Keep every HV/DC source
> physically disconnected and disabled.

## 1. Required configuration

Before using this runbook:

- complete the PCB assembly inspection;
- obtain clean ERC and DRC results for the committed KiCad revision;
- compile and upload the committed Arduino sketch;
- verify the State-A, State-B and 5% HLC feedback paths with bench loads;
- install and test the Raspberry Pi software;
- configure the correct serial device, GPIOs and network interface;
- configure exactly one EVSE-side SLAC owner: the `plc-utils` `evse` process
  started by `monday_ops.sh`;
- create the local environment, operations and SLAC configuration files;
- confirm that no raw run directory or local secret will be added to Git.

The final PCB vehicle-interface mapping is:

| Terminal | Function |
| --- | --- |
| `J2.1` | `EVSE_CP_OUT` to charging-cable CP |
| `J2.2` | `EVSE_PP_OUT` to the documented PP connection, when used |
| `J2.3` | `ISO_GND` to charging-cable PE/reference |
| `J2.4` | Not connected |

Confirm the cable pinout independently. Do not infer connector orientation from
wire colour.

## 2. Select the protocol boundary

The local `.env.monday-real-ev` file contains:

```text
MONDAY_PRECHARGE_PROBE=0
```

Use `0` for the normal fail-safe mode. In that mode, reaching CableCheck and
receiving an automatic external STOP is a successful communication result.

The final thesis experiment used `MONDAY_PRECHARGE_PROBE=1` to observe the
vehicle's first `PreChargeReq`. That option emulates CableCheck readiness only
at the protocol layer. It performs no isolation measurement, closes no physical
DC contactor and produces no output voltage. The first requested charging
target is rejected and triggers a latched STOP.

Enabling the probe is permitted only on the documented communication-only rig
with every HV/DC source absent. Record the chosen value in the lab notes before
the test.

## 3. Physical configuration with all power removed

1. Remove the State-B and State-C breadboard loads. The real EV supplies the CP
   load.
2. Leave PCB `JP2` open so the designed PLC coupling capacitors remain in the
   circuit.
3. Connect the Devolo coupling pair to PCB `J1.1` (PLC signal) and `J1.2`
   (`ISO_GND`/return). Confirm the Devolo terminal orientation from its
   documentation or a verified continuity check.
4. Connect PCB `J2.1` (`EVSE_CP_OUT`) to the cable CP conductor.
5. Connect PCB `J2.2` (`EVSE_PP_OUT`) only according to the documented PP
   arrangement for the test cable.
6. Connect PCB `J2.3` (`ISO_GND`) to the cable PE/reference conductor.
7. Keep the Raspberry-Pi-to-Devolo Ethernet connection installed. It is
   independent of the two-wire PLC coupling pair.
8. Add strain relief and inspect for loose strands or unintended shorts.
9. Confirm that every HV/DC source is absent and disabled.

Recommended unpowered checks include:

- continuity from PCB `J1.2` to `J2.3`;
- no hard short from `J1.1` to `J1.2`;
- no hard short from `J2.1` to `J2.3`;
- the cable CP, PP and PE conductors reach the intended J2 terminals.

With `JP2` open, do not expect DC continuity through the series PLC coupling
capacitors. Keep the J3-to-J1 coupling pair short and twisted.

## 4. Start the low-voltage test environment

Power only the PCB low-voltage electronics, Raspberry Pi, Arduino and Devolo
modem. Connect the operator laptop to the Pi management network.

In one SSH session, run:

```bash
ssh <pi-user>@<pi-host>

set -a
. /path/to/monday-ops.env
set +a

/path/to/monday_ops.sh test-day
```

`test-day` performs the software/network preflight, creates a timestamped
evidence directory, starts packet capture, Redis and the SECC, waits for UDP
15118 and opens the four-pane cockpit.

If preflight fails, keep the EV disconnected. Correct the reported problem and
run the preflight again.

| Pane | Function |
| --- | --- |
| Large left | Interactive console and sole serial/GPIO owner |
| Upper right | Decoded CP state and freshness monitor |
| Middle right | Sole `plc-utils` EVSE SLAC owner |
| Lower right | Live SECC application log |

Select a pane by clicking it or with `Ctrl+b` followed by an arrow key. Use
`Ctrl+b`, then `z`, to zoom or restore a pane. Use `Ctrl+b`, then uppercase
`M`, for the guarded operator menu.

If SSH disconnects, reconnect and run:

```bash
/path/to/monday_ops.sh cockpit
```

## 5. Establish State A

At the `bench>` prompt, enter one command at a time:

```text
reset
remote on
a
status
```

Before connecting the EV, require:

```text
CP_MODE=A_POSITIVE_DC
REMOTE=ON
FB_PAIR=00
FB_STABLE=YES
Pi relay command: ON
STOP latch: OFF
```

The CP monitor must repeatedly show usable `A1`. Do not enter `HLC` yet.

The SLAC pane must show a successful `CM_SET_KEY` result and then the
unoccupied/listening state. A repeating `CM_SLAC_PARAM.REQ ?` line means the
listener is waiting; it does not prove that an EV has transmitted a request.

## 6. Connect the EV and verify State B

1. Keep the console in State A and the SLAC listener running.
2. Connect the charging connector to the EV.
3. Wait for the CP state to become stable.
4. Require both views to agree before starting HLC.

Console:

```text
FB_PAIR=10 FB_STABLE=YES
```

CP monitor:

```text
CP=B1 usable=True
```

If B1 is not stable, use the operator menu to save a snapshot and request
fail-safe STOP. Do not change wiring while powered.

## 7. Start HLC once

Only after stable B1, enter:

```text
hlc
status
```

Require:

```text
CP_MODE=PWM
CP_POSITIVE_DUTY=5.0%
REMOTE=ON
FB_PAIR=10
FB_STABLE=YES
```

and:

```text
CP=B2 usable=True
```

The validated feedback mapping may later change to `FB_PAIR=11`, decoded C2,
when the vehicle requests the ready-to-charge CP state. This is a normal
vehicle-controlled transition; it is not the initial State-B acceptance check.

Observe the evidence in this order:

1. HomePlug Green PHY/SLAC frames (`0x88e1`);
2. a remote PLC station;
3. IPv6 and SDP;
4. TCP connection;
5. SupportedAppProtocol negotiation;
6. ISO 15118 application messages;
7. external STOP at the selected protocol boundary.

Expected boundary by mode:

| Probe value | Expected result |
| --- | --- |
| `0` | `No_IMD`/`EVSE_NotReady`; STOP when CableCheck cannot be completed |
| `1` | Test-only CableCheck status; first PreCharge target blocked; latched STOP |

The validated probe session received a target of 303.2 V and 1.0 A, blocked it,
returned a failed PreCharge response and restored the host to the safe state.
Those values are protocol observations, not emulator output ratings.

## 8. Stop conditions

Request STOP immediately for any of the following:

- stale, unstable or `UNKNOWN` CP feedback;
- disagreement between physical indications and console state;
- unexpected relay behaviour;
- a second serial/GPIO owner or second SLAC owner;
- missing capture or SECC logging;
- loose wiring, abnormal heat, odor, smoke or arcing;
- any connected HV/DC source;
- progression beyond the selected test boundary without the expected STOP.

If the console cannot confirm relay OFF within eight seconds, remove PCB
low-voltage power.

## 9. Normal shutdown

At the console:

```text
session stop
status
exit
```

Confirm `Pi relay command: OFF`. Open the operator menu and select final
shutdown, or run the shutdown command from a separate management shell if the
validated procedure requires it:

```bash
/path/to/monday_ops.sh shutdown
```

The shutdown procedure requests or verifies the safe CP state, stops capture,
collects state and logs, stops services and creates `SHA256SUMS`.

Display the evidence paths with:

```bash
/path/to/monday_ops.sh paths
```

Copy the complete run folder to private storage before another attempt. Record
the probe value, EV model, visible vehicle message, operator observations and
connection/disconnection times in the laboratory notes.

Do not commit the raw run folder. It can contain vehicle identifiers, MAC
addresses, PLC keys, host information and packet payloads.

## 10. Optional final bench rehearsal

This rehearsal checks the integrated cockpit against the previously verified
State-B load. It is not a substitute for component qualification.

1. Complete shutdown and remove all low-voltage power.
2. Disconnect the EV and the Devolo coupling pair.
3. Connect only the verified State-B bench load between `J2.1` and `J2.3`.
4. Attach the oscilloscope using the validated measurement points.
5. Start `monday_ops.sh test-day` and establish State A.
6. Require stable `FB_PAIR=10`, decoded B1 and the expected State-B plateau.
7. Enter HLC once and require 1 kHz/5%, stable `FB_PAIR=10` and decoded B2.
8. Save a snapshot and perform the confirmed safe shutdown.
9. Remove power before changing the bench load or restoring the real-EV wiring.

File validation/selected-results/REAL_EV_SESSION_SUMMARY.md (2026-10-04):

# Sanitized real-EV session summary

This document summarizes the four integrated vehicle sessions used for the
communication results in Chapter 6 of the thesis. Session numbering follows the
thesis: Sessions 2–5 were recorded on 25 September 2026.

The raw packet captures and complete cockpit archives are deliberately not part
of the repository. They contain link-layer and application identifiers, PLC
network material, host details and packet payloads. The source evidence is kept
in private storage; only the sanitized outcome matrix is published here.

## Outcome matrix

Times below are local laboratory time (Europe/Berlin, UTC+02:00).

| Thesis session | Capture label | Actual captured traffic | HomePlug frames | TCP payload segments | Highest confirmed application result | Termination |
| --- | --- | --- | ---: | ---: | --- | --- |
| 2 | `20260925T152722` | 15:28:00–15:28:19 | 39 | 18 | `PreChargeReq` received and failed `PreChargeRes` sent | SECC safety logic blocked the requested target and ended the session |
| 3 | `20260925T161404` | 16:15:32–16:15:44 | 39 | 4 | `SessionSetupRes` sent; SECC entered `ServiceDiscovery` | TCP peer closed the connection before `ServiceDiscoveryReq` |
| 4 | `20260925T163003` | 16:30:17–16:30:36 | 39 | 19 | `PreChargeReq` received and failed `PreChargeRes` sent | SECC safety logic blocked the requested target and ended the session |
| 5 | `20260925T163915` | 16:41:08–16:41:26 | 39 | 19 | `PreChargeReq` received and failed `PreChargeRes` sent | SECC safety logic blocked the requested target and ended the session |

The 19 TCP payload segments in Sessions 4 and 5 include a retransmitted
`PreChargeRes`; the SECC application log records one generated response per
session.

## Findings

- EVSE-side SLAC completed in all four recorded sessions.
- SDP selected TCP without TLS in all four sessions.
- ISO 15118-2 was successfully negotiated in all four sessions.
- Three independent sessions reached the thesis endpoint: the first
  `PreChargeReq` followed by the deliberately failed `PreChargeRes`.
- Session 3 was not a PreCharge failure. The vehicle-side TCP peer closed the
  connection after `SessionSetupRes`, while the SECC was waiting in
  `ServiceDiscovery`.
- No physical pre-charge or energy transfer took place in any session.

In the three endpoint sessions, the vehicle requested approximately 303.2 V
and 1.0 A. The controller rejected the target, requested the host fail-safe
STOP and returned the failed protocol response. These values are observations
from the vehicle request, not electrical output ratings of the emulator.

## Private evidence correlation

The following files are retained outside Git. Their hashes allow the private
evidence supplied for review to be checked against the files used to produce
this summary.

| Session | Private packet capture | SHA-256 | Private cockpit archive | SHA-256 |
| --- | --- | --- | --- | --- |
| 2 | `precharge_pilot_20260925T152722.pcap` | `b926a9a125a0aac29f2084cd59858d7af2c89f49af7d701558f798a328f45740` | `monday-test-20260925-152950.tar.gz` | `4fedf52a68d74bf341bb6c673713d6923a8859c7f63e90b1219200d06884a1d7` |
| 3 | `precharge_pilot_20260925T161404.pcap` | `45d7ad0859d58865deb4f4b94dea07223c49f4df7540d0afb662204b4f28fc8d` | `monday-test-20260925-161749.tar.gz` | `3f93a36922e5305bafa8b1cbb8ae0c9e5b1029f38511b1d5d62b66d1785990e3` |
| 4 | `precharge_pilot_20260925T163003.pcap` | `6a407a9bff8a7918118347ce86c75b32878c168209e383a3ed9be6e82611df8d` | `monday-test-20260925-163138.tar.gz` | `7ff62f4aaf49cdba5bfe0b28580cfeb34804f572e0c05715cf147b1fcd07da6e` |
| 5 | `precharge_pilot_20260925T163915.pcap` | `4f29650ac94579b679a4e29ccea3770ceb56abb5c53ed57421af419ac350f0be` | `monday-test-20260925-164910.tar.gz` | `7b7fb2766953a7b684dc6882cd47f8e9b735cc236d40057cc3326895bf83a2fe` |

An earlier cockpit archive ending in `151558` represents a separate preliminary
attempt. It is not one of the four sessions summarized in Chapter 6 and is not
included in the outcome matrix above.

## Publication boundary

Do not commit the raw PCAP files, raw cockpit archives, unredacted SECC logs or
state snapshots. If packet-level evidence is required for a reviewer, provide
it privately or create a separately reviewed and sanitized extract. Removing a
raw capture after committing it does not remove it from Git history.

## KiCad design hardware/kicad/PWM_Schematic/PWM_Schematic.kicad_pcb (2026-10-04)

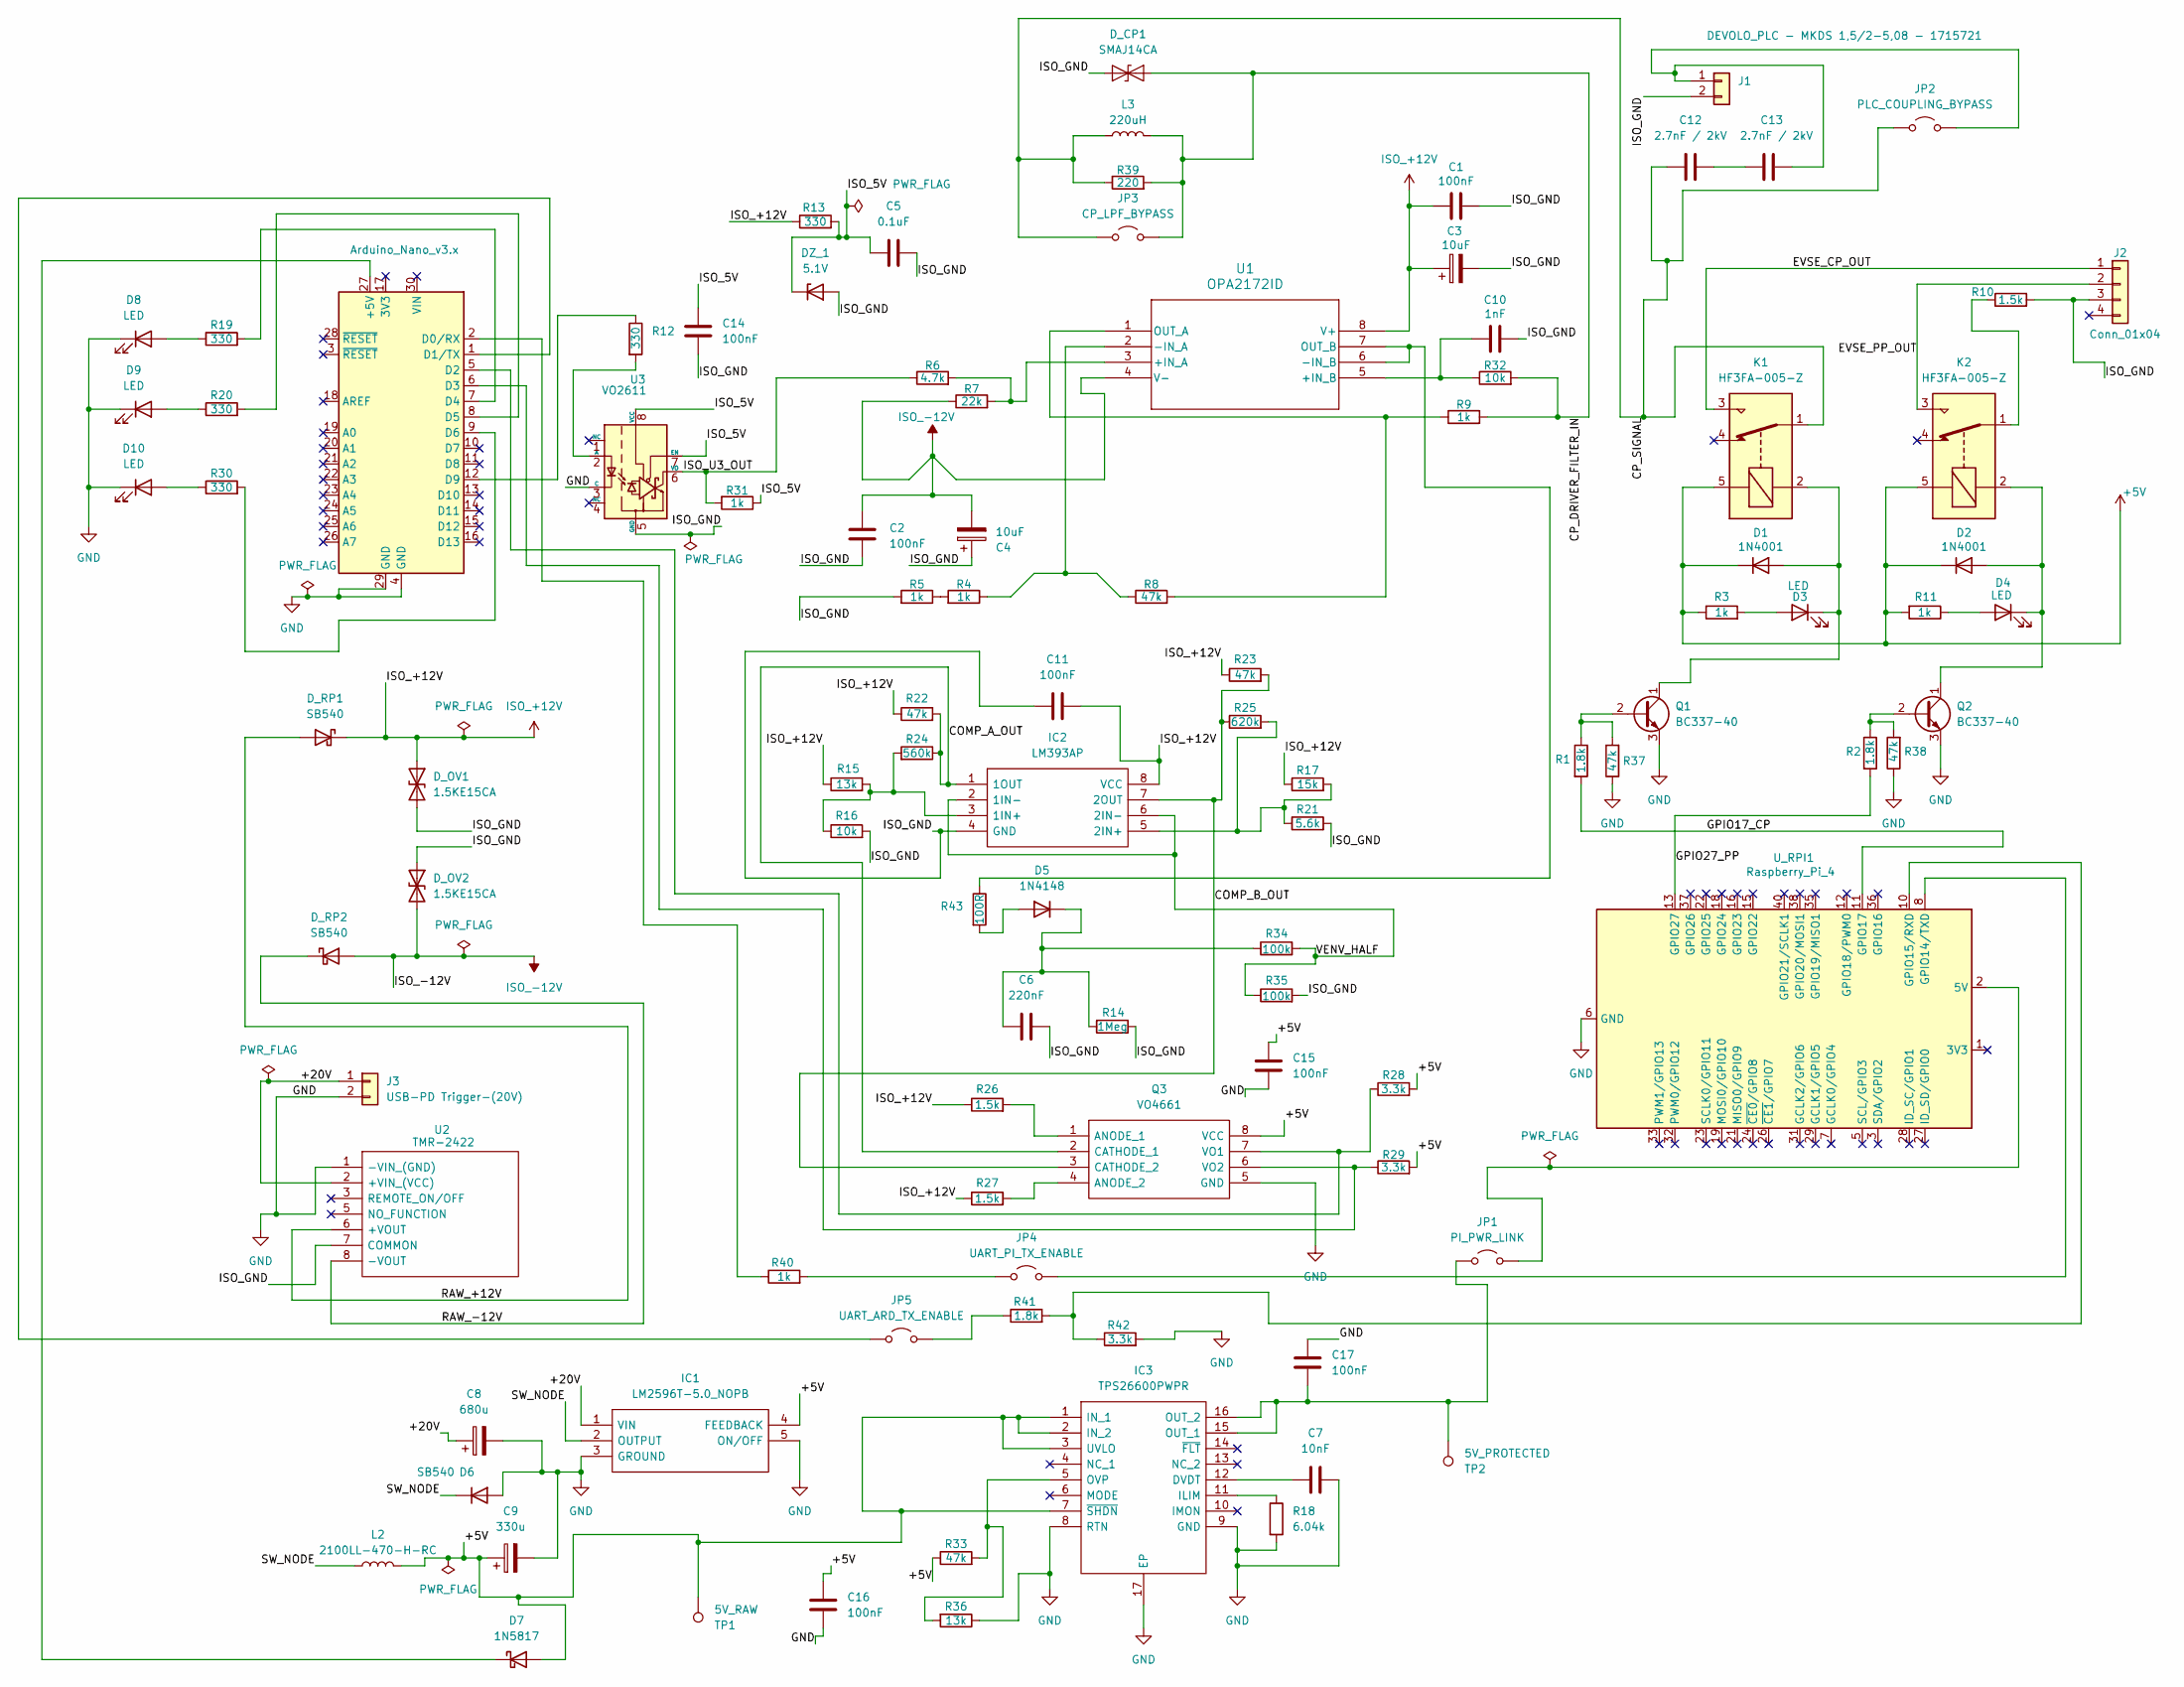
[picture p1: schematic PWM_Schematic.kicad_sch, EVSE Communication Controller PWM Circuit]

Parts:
A1: Arduino_Nano_v3.x; Arduino_Nano
C1, C2, C11, C14, C15: 100nF; C_Disc_D5.0mm_W2.5mm_P2.50mm
C3, C4: 10uF; CP_Radial_D5.0mm_P2.00mm
C5: 0.1uF; C_Disc_D5.0mm_W2.5mm_P2.50mm
C6: 220nF; C_Universal_P2.54_L5.5_W3.5
C7: 10nF; C_Disc_D5.0mm_W2.5mm_P2.50mm
C8: 680u; CP_Radial_D12.5mm_P5.00mm
C9: 330u; CP_Radial_D10.0mm_P5.00mm
C10: 1nF; C_Disc_D5.0mm_W2.5mm_P2.50mm
C12, C13: 2.7nF / 2kV; C_Rect_L18.0mm_W5.0mm_P15.00mm_FKS3_FKP3; MPN R75UI127050H4J
C16, C17: 100nF; C_0805_2012Metric
D1, D2: 1N4001; D_DO-41_SOD81_P7.62mm_Horizontal
D3, D4, D8, D9, D10: LED; LED_D5.0mm
D5: 1N4148; D_DO-35_SOD27_P7.62mm_Horizontal
D6: SB540; D_DO-201AD_P15.24mm_Horizontal
D7: 1N5817; D_DO-41_SOD81_P7.62mm_Horizontal
DZ_1: 5.1V; D_DO-35_SOD27_P7.62mm_Horizontal
D_CP1: SMAJ14CA; D_SMA; MPN SMAJ14CA
D_OV1, D_OV2: 1.5KE15CA; D_DO-201AD_P15.24mm_Horizontal
D_RP1, D_RP2: SB540; D_DO-201AD_P15.24mm_Horizontal
IC1: LM2596T-5.0_NOPB; TO170P470X1028X2117-5P; Mouser Part Number 926-LM2596T-5.0/NOPB
IC2: LM393AP; LM393_DIP8_AISLER_0p30mm_Annular; Mouser Part Number 595-LM393P
IC3: TPS26600PWPR; HTSSOP-16-1EP_4.4x5mm_P0.65mm_EP3x3mm; Mouser Part Number 595-TPS26600PWPR
J1: DEVOLO_PLC - MKDS 1,5/2-5,08 - 1715721; TerminalBlock_Universal_1x02_P5.08_Phoenix_Molex
J2: Conn_01x04; TerminalBlock_Phoenix_MPT-0,5-4-2.54_1x04_P2.54mm_Horizontal
J3: USB-PD Trigger-(20V); PinSocket_1x02_P2.54mm_Vertical
JP1: PI_PWR_LINK; PinHeader_1x02_P2.54mm_Vertical
JP2: PLC_COUPLING_BYPASS; PinHeader_1x02_P2.54mm_Vertical
JP3: CP_LPF_BYPASS; PinHeader_1x02_P2.54mm_Vertical
JP4: UART_PI_TX_ENABLE; PinHeader_1x02_P2.54mm_Vertical
JP5: UART_ARD_TX_ENABLE; PinHeader_1x02_P2.54mm_Vertical
K1: HF3FA-005-Z; Relay_SPDT_SANYOU_SRD_Series_Form_C Modified_1
K2: HF3FA-005-Z; Relay_SPDT_SANYOU_SRD_Series_Form_C_Modified
L2: 2100LL-470-H-RC; L2_AISLER_0p30mm_Annular
L3: 220uH; L_Wurth_7447020_P7.00mm_1; MPN 7447020
Q1, Q2: BC337-40; TO-92_Inline_Wide
Q3: VO4661; VO4661_DIP8_AISLER_0p30mm_Annular; Mouser Part Number 782-VO4661
R1, R2, R41: 1.8k; R_Axial_DIN0207_L6.3mm_D2.5mm_P7.62mm_Horizontal
R3, R4, R5, R9, R11, R31, R40: 1k; R_Axial_DIN0207_L6.3mm_D2.5mm_P7.62mm_Horizontal
R6: 4.7k; R_Axial_DIN0207_L6.3mm_D2.5mm_P7.62mm_Horizontal
R7: 22k; R_Axial_DIN0207_L6.3mm_D2.5mm_P7.62mm_Horizontal
R8, R22, R23, R33, R37, R38: 47k; R_Axial_DIN0207_L6.3mm_D2.5mm_P7.62mm_Horizontal
R10, R26, R27: 1.5k; R_Axial_DIN0207_L6.3mm_D2.5mm_P7.62mm_Horizontal
R12, R13, R19, R20, R30: 330; R_Axial_DIN0207_L6.3mm_D2.5mm_P7.62mm_Horizontal
R14: 1Meg; R_Axial_DIN0207_L6.3mm_D2.5mm_P7.62mm_Horizontal
R15, R36: 13k; R_Axial_DIN0207_L6.3mm_D2.5mm_P7.62mm_Horizontal
R16, R32: 10k; R_Axial_DIN0207_L6.3mm_D2.5mm_P7.62mm_Horizontal
R17: 15k; R_Axial_DIN0207_L6.3mm_D2.5mm_P7.62mm_Horizontal
R18: 6.04k; R_Axial_DIN0207_L6.3mm_D2.5mm_P7.62mm_Horizontal
R21: 5.6k; R_Axial_DIN0207_L6.3mm_D2.5mm_P7.62mm_Horizontal
R24: 560k; R_Axial_DIN0207_L6.3mm_D2.5mm_P7.62mm_Horizontal
R25: 620k; R_Axial_DIN0207_L6.3mm_D2.5mm_P7.62mm_Horizontal
R28, R29, R42: 3.3k; R_Axial_DIN0207_L6.3mm_D2.5mm_P7.62mm_Horizontal
R34, R35: 100k; R_Axial_DIN0207_L6.3mm_D2.5mm_P7.62mm_Horizontal
R39: 220; R_Axial_DIN0207_L6.3mm_D2.5mm_P7.62mm_Horizontal
R43: 100R; R_Axial_DIN0207_L6.3mm_D2.5mm_P7.62mm_Horizontal
TP1: 5V_RAW; TestPoint_THTPad_D2.0mm_Drill1.0mm
TP2: 5V_PROTECTED; TestPoint_THTPad_D2.0mm_Drill1.0mm
U1: OPA2172ID; D8_TEX
U2: TMR-2422; Converter_DCDC_TRACO_TEC2-12xxWI_24xxWI_48xxWI_THT; Mouser Part Number 495-TMR-2422
U3: VO2611; DIP-8_W7.62mm
U_RPI1: Raspberry_Pi_4; PinSocket_2x20_P2.54mm_Vertical

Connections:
+5V: C9.1, C15.1, C16.1, D1.1 (K), D2.1 (K), D7.2 (A), IC1.4 (FEEDBACK), IC3.1 (IN_1), IC3.2 (IN_2), IC3.3 (UVLO), IC3.7 (~SHDN), K1.5, K2.5, L2.2, Q3.8 (VCC), R3.1, R11.2, R28.2, R29.2, R33.1, TP1.1 (1_1)
/+20V: C8.1, IC1.1 (VIN), J3.1, U2.2 (+VIN_(VCC))
/COMP_A_OUT: IC2.1 (1OUT), Q3.2 (CATHODE_1), R22.2, R24.1
/COMP_B_OUT: IC2.7 (2OUT), Q3.3 (CATHODE_2), R23.2, R25.1
/CP_DRIVER_FILTER_IN: D_CP1.2 (A2), JP3.2 (B), L3.2, R9.2, R32.2, R39.2
/CP_SIGNAL: C12.1, JP2.1 (A), JP3.1 (A), K1.1, L3.1, R39.1
/EVSE_CP_OUT: J2.1, K1.3
/EVSE_PP_OUT: J2.2, K2.3
/GPIO17_CP: R1.2, U_RPI1.11 (GPIO17)
/GPIO27_PP: R2.2, U_RPI1.13 (GPIO27)
/ISO_5V: C5.1, C14.1, DZ_1.1 (K), R13.2, R31.1, U3.7 (EN), U3.8 (VCC)
/ISO_GND: C1.1, C2.2, C3.2, C4.1, C5.2, C6.2, C10.2, C11.1, C14.2, DZ_1.2 (A), D_CP1.1 (A1), D_OV1.2 (A2), D_OV2.1 (A1), IC2.4 (GND), J1.2, J2.3, R5.2, R10.2, R14.1, R16.2, R21.2, R35.2, U2.7 (COMMON), U3.5 (GND)
/ISO_U3_OUT: R6.1, R31.2, U3.6 (VO)
/RAW_+12V: D_RP1.2 (A), U2.6 (+VOUT)
/RAW_-12V: D_RP2.1 (K), U2.8 (-VOUT)
/SW_NODE: D6.1 (K), IC1.2 (OUTPUT), L2.1
/VENV_HALF: IC2.2 (1IN-), IC2.6 (2IN-), R34.2, R35.1
GND: A1.4 (GND), A1.29 (GND), C7.2, C8.2, C9.2, C15.2, C16.2, C17.1, D6.2 (A), D8.1 (K), D9.1 (K), D10.1 (K), IC1.3 (GROUND), IC1.5 (ON/OFF), IC3.8 (RTN), IC3.9 (GND), IC3.17 (EP), J3.2, Q1.3 (E), Q2.3 (E), Q3.5 (GND), R18.2, R36.1, R37.1, R38.1, R42.2, U2.1 (-VIN_(GND)), U3.3 (C), U_RPI1.6 (GND), U_RPI1.9 (GND), U_RPI1.14 (GND), U_RPI1.20 (GND), U_RPI1.25 (GND), U_RPI1.30 (GND), U_RPI1.34 (GND), U_RPI1.39 (GND)
ISO_+12V: C1.2, C3.1, C11.2, D_OV1.1 (A1), D_RP1.1 (K), IC2.8 (VCC), R13.1, R15.1, R17.1, R22.1, R23.1, R26.1, R27.1, U1.8 (V+)
ISO_-12V: C2.1, C4.2, D_OV2.2 (A2), D_RP2.2 (A), R7.1, U1.4 (V-)
unnamed: A1.27 (+5V), D7.1 (K)
unnamed: A1.2 (D0/RX), R40.1
unnamed: A1.1 (D1/TX), JP5.1 (A)
unnamed: A1.5 (D2), Q3.7 (VO1), R28.1
unnamed: A1.6 (D3), Q3.6 (VO2), R29.1
unnamed: A1.7 (D4), R19.2
unnamed: A1.8 (D5), R20.2
unnamed: A1.9 (D6), R30.2
unnamed: A1.12 (D9), R12.1
unnamed: C12.2, C13.1
unnamed: D1.2 (A), D3.1 (K), K1.2, Q1.1 (C)
unnamed: D2.2 (A), D4.1 (K), K2.2, Q2.1 (C)
unnamed: D3.2 (A), R3.2
unnamed: D4.2 (A), R11.1
unnamed: D5.2 (A), R43.2
unnamed: C6.1, D5.1 (K), R14.2, R34.1
unnamed: D8.2 (A), R19.1
unnamed: D9.2 (A), R20.1
unnamed: D10.2 (A), R30.1
unnamed: IC2.3 (1IN+), R15.2, R16.1, R24.2
unnamed: IC2.5 (2IN+), R17.2, R21.1, R25.2
unnamed: C7.1, IC3.12 (DVDT)
unnamed: IC3.11 (ILIM), R18.1
unnamed: C17.2, IC3.15 (OUT_1), IC3.16 (OUT_2), JP1.1 (A), TP2.1 (1_1)
unnamed: IC3.5 (OVP), R33.2, R36.2
unnamed: C13.2, J1.1, JP2.2 (B)
unnamed: JP1.2 (B), U_RPI1.2 (5V), U_RPI1.4 (5V)
unnamed: JP4.1 (A), R40.2
unnamed: JP4.2 (B), U_RPI1.8 (GPIO14/TXD)
unnamed: JP5.2 (B), R41.1
unnamed: K2.1, R10.1
unnamed: Q1.2 (B), R1.1, R37.2
unnamed: Q2.2 (B), R2.1, R38.2
unnamed: Q3.1 (ANODE_1), R26.2
unnamed: Q3.4 (ANODE_2), R27.2
unnamed: R4.2, R5.1
unnamed: R6.2, R7.2, U1.3 (+IN_A)
unnamed: C10.1, R32.1, U1.5 (+IN_B)
unnamed: R4.1, R8.1, U1.2 (-IN_A)
unnamed: R43.1, U1.6 (-IN_B), U1.7 (OUT_B)
unnamed: R8.2, R9.1, U1.1 (OUT_A)
unnamed: R12.2, U3.2 (A)
unnamed: R41.2, R42.1, U_RPI1.10 (GPIO15/RXD)

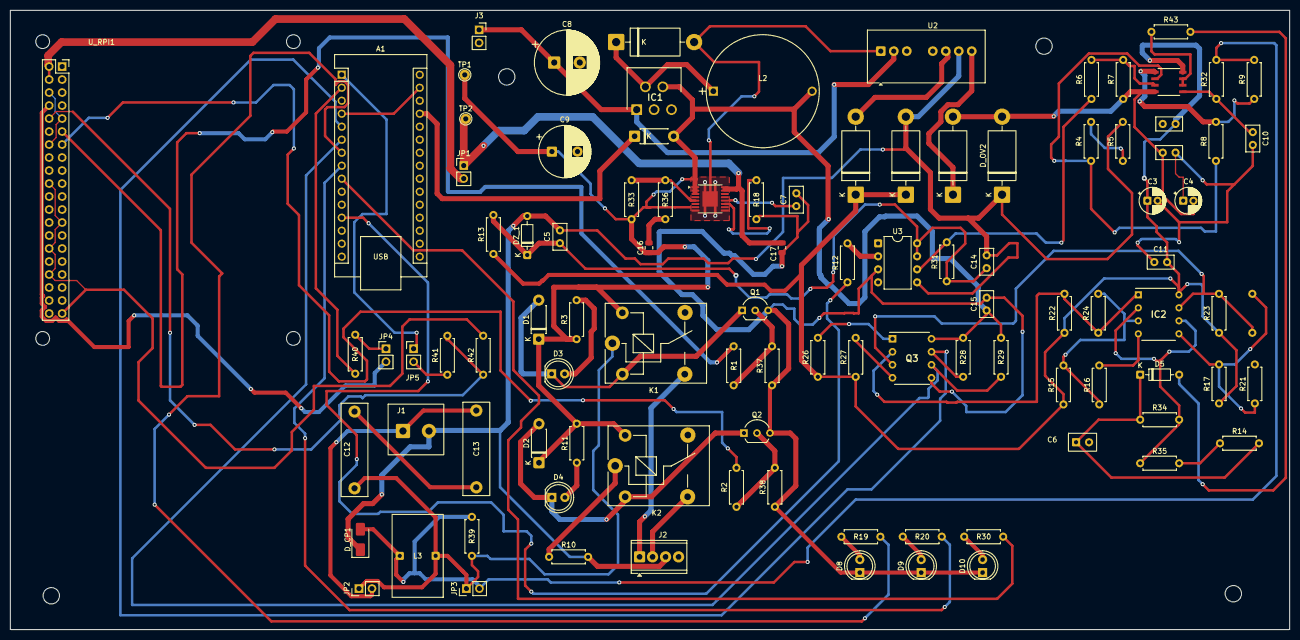
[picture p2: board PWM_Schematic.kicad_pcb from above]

Board: 2 copper layers, 250.0 x 121.0 mm, 101 parts (1 on the bottom side), 63 nets.

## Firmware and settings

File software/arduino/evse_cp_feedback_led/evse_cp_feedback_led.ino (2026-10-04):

/*
  EVSE control-pilot controller for Arduino Nano (ATmega328P, 16 MHz)

  Feedback-monitor bench build, September 2026.
  Q3 receiver: pin7 -> Nano D2, pin6 -> Nano D3, referenced to main GND.
  External pull-ups R28/R29 fitted; these pins are INPUT, never OUTPUT.
  Pi owns K1/K2 via GPIO17/27. CONTACTORS=OFF is retained only as a
  legacy protocol field, NOT measured Pi relay-contact feedback.
  Diagnostic LEDs: D4 mirrors sampled D2, D5 mirrors sampled D3,
  D6 is HIGH while feedback has not satisfied the 20 ms settling test.
  LEDs show sampled feedback only; fast transitions may not be visible.
  Power and isolated-rail configuration must match the validated bench setup.
  This monitor does not authorize charging or implement vehicle interlocks.

  PCB signal path:
    Arduino D9 -> R12 (330 ohm) -> U3 (VO2611) input LED -> main GND

  IMPORTANT POLARITY:
    U3 inverts D9. Therefore:
      D9 LOW       -> eventual CP +12 V (State A command)
      D9 HIGH      -> eventual CP -12 V (State F/disabled command)
      CP duty 5 %  -> D9 is HIGH for 95 % and LOW for 5 %

  Serial Monitor settings: 115200 baud, line ending "Newline".

  Commands:
    HELP
    STATUS
    A                 steady positive CP command (eventual +12 V)
    HLC               1 kHz, 5.0 % positive CP duty
    PWM <duty>        test/AC PWM: 5.0 or 10.0...96.0 percent CP duty
    SESSION START     same as HLC
    SESSION STOP      contactors off, return to State A command
    DISABLE           contactors off, steady negative command
    FAULT <text>      latch fault, contactors off, steady negative command
    RESET             clear fault and return to State A command
    REMOTE ON         enable 3 s host-heartbeat supervision
    REMOTE OFF        disable host-heartbeat supervision
    HB                host heartbeat
    PING <text>       replies ACK PING <text>

  State B/C/D/E are measured EV responses, not voltages generated directly
  by the Arduino. The EV resistor network pulls the positive CP peak from
  +12 V to approximately +9/+6/+3/0 V. Automatic feedback decoding will be
  assigned only after comparator thresholds and polarity are measured.
  STATUS appends FB_D2/FB_D3 (raw), FB_PAIR (settled D2,D3),
  FB_STABLE and FB_CHANGES. No unsolicited messages are emitted.
  A stable bit pair is NOT proof of a valid CP voltage or connected EV.
*/

#include <Arduino.h>
#include <ctype.h>
#include <stdlib.h>
#include <string.h>

#if F_CPU != 16000000UL
#error "This Timer1 configuration requires a 16 MHz Arduino Nano."
#endif

namespace Hardware {
constexpr uint8_t CP_PWM_PIN = 9;       // OC1A
constexpr uint8_t FEEDBACK_D2_PIN = 2;
constexpr uint8_t FEEDBACK_D3_PIN = 3;
constexpr uint8_t INDICATOR_D4_PIN = 4;
constexpr uint8_t INDICATOR_D5_PIN = 5;
constexpr uint8_t INDICATOR_D6_PIN = 6;
}

namespace Timing {
constexpr uint16_t TIMER1_TOP = 1999;  // 16 MHz / 8 / (1999 + 1) = 1 kHz
constexpr uint32_t HEARTBEAT_TIMEOUT_MS = 3000;
}

enum class CpMode : uint8_t {
  STATE_A_POSITIVE,
  PWM_ACTIVE,
  STATE_F_NEGATIVE,
  FAULT_LATCHED
};

CpMode cpMode = CpMode::STATE_A_POSITIVE;
uint16_t cpDutyTenthPercent = 1000;  // 100.0 % positive for steady State A
bool faultLatched = false;
bool remoteSupervision = false;
uint32_t lastHeartbeatMs = 0;
char faultReason[33] = "NONE";

char commandBuffer[81];
uint8_t commandLength = 0;

void holdIndicatorsOff() {
  digitalWrite(Hardware::INDICATOR_D4_PIN, LOW);
  digitalWrite(Hardware::INDICATOR_D5_PIN, LOW);
  digitalWrite(Hardware::INDICATOR_D6_PIN, LOW);
}

void disconnectTimer1Output() {
  TCCR1A &= static_cast<uint8_t>(~(_BV(COM1A1) | _BV(COM1A0)));
}

// U3 is inverting, so D9 LOW eventually commands positive CP.
void commandSteadyPositive() {
  const uint8_t savedSreg = SREG;
  cli();
  disconnectTimer1Output();
  digitalWrite(Hardware::CP_PWM_PIN, LOW);
  TCNT1 = 0;
  SREG = savedSreg;

  cpMode = CpMode::STATE_A_POSITIVE;
  cpDutyTenthPercent = 1000;
}

// U3 is inverting, so D9 HIGH eventually commands negative CP.
void commandSteadyNegative(bool dueToFault) {
  const uint8_t savedSreg = SREG;
  cli();
  disconnectTimer1Output();
  digitalWrite(Hardware::CP_PWM_PIN, HIGH);
  TCNT1 = 0;
  SREG = savedSreg;

  cpMode = dueToFault ? CpMode::FAULT_LATCHED : CpMode::STATE_F_NEGATIVE;
  cpDutyTenthPercent = 0;
}

bool dutyIsAllowed(uint16_t dutyTenthPercent) {
  // 5.0 % is the HLC request. Conventional PWM is restricted here to
  // 10.0...96.0 %. Values between these regions are intentionally rejected.
  return dutyTenthPercent == 50 ||
         (dutyTenthPercent >= 100 && dutyTenthPercent <= 960);
}

void commandCpPwm(uint16_t positiveDutyTenthPercent) {
  // CP duty describes the eventual +12 V duration. Since U3 inverts D9,
  // the Arduino HIGH fraction is the complement of the requested CP duty.
  const uint32_t positiveCounts =
      (static_cast<uint32_t>(Timing::TIMER1_TOP + 1U) *
       positiveDutyTenthPercent + 500U) /
      1000U;
  const uint16_t d9HighCounts =
      static_cast<uint16_t>((Timing::TIMER1_TOP + 1U) - positiveCounts);

  const uint8_t savedSreg = SREG;
  cli();

  // Fast PWM, mode 14: TOP = ICR1, non-inverting OC1A, prescaler = 8.
  // At 5.0 % CP duty, OCR1A = 1900: D9 is HIGH for about 950 us and
  // LOW for about 50 us. U3 later converts this to +12 V for 50 us.
  TCCR1A = 0;
  TCCR1B = 0;
  TCNT1 = 0;
  ICR1 = Timing::TIMER1_TOP;
  OCR1A = d9HighCounts;
  TCCR1A = _BV(COM1A1) | _BV(WGM11);
  TCCR1B = _BV(WGM13) | _BV(WGM12) | _BV(CS11);

  SREG = savedSreg;

  cpMode = CpMode::PWM_ACTIVE;
  cpDutyTenthPercent = positiveDutyTenthPercent;
}

void copyFaultReason(const char *reason) {
  if (reason == nullptr || *reason == '\0') {
    reason = "UNSPECIFIED";
  }
  strncpy(faultReason, reason, sizeof(faultReason) - 1U);
  faultReason[sizeof(faultReason) - 1U] = '\0';
}

void latchFault(const char *reason) {
  faultLatched = true;
  copyFaultReason(reason);
  commandSteadyNegative(true);
  Serial.print(F("FAULT LATCHED: "));
  Serial.println(faultReason);
}

void clearFault() {
  faultLatched = false;
  copyFaultReason("NONE");
  remoteSupervision = false;
  commandSteadyPositive();
  Serial.println(F("ACK RESET; CP=A; CONTACTORS=OFF; REMOTE=OFF"));
}

const __FlashStringHelper *modeName() {
  switch (cpMode) {
    case CpMode::STATE_A_POSITIVE:
      return F("A_POSITIVE_DC");
    case CpMode::PWM_ACTIVE:
      return F("PWM");
    case CpMode::STATE_F_NEGATIVE:
      return F("F_NEGATIVE_DC");
    case CpMode::FAULT_LATCHED:
      return F("FAULT_NEGATIVE_DC");
  }
  return F("UNKNOWN");
}

void printDuty(uint16_t tenthPercent) {
  Serial.print(tenthPercent / 10U);
  Serial.print('.');
  Serial.print(tenthPercent % 10U);
}

// Commissioning filter only: two digital levels, not CP state decoding.
// This software cannot distinguish lost isolated power from some low-envelope
// conditions. Do not use FB_PAIR as a charging permission.
constexpr uint32_t FEEDBACK_SETTLE_MS = 20;
uint8_t feedbackRaw = 0;
uint8_t feedbackCandidate = 0;
uint8_t feedbackSettled = 0;
bool feedbackInitialized = false;
bool feedbackHasSettled = false;
uint32_t feedbackCandidateSince = 0;
uint32_t feedbackChanges = 0;

bool feedbackIsStable(uint32_t now) {
  return feedbackHasSettled && feedbackRaw == feedbackSettled &&
      static_cast<uint32_t>(now - feedbackCandidateSince) >= FEEDBACK_SETTLE_MS;
}

void serviceFeedback() {
  const uint32_t now = millis();
  feedbackRaw = (digitalRead(Hardware::FEEDBACK_D2_PIN) == HIGH ? 2U : 0U) |
                (digitalRead(Hardware::FEEDBACK_D3_PIN) == HIGH ? 1U : 0U);
  if (!feedbackInitialized || feedbackRaw != feedbackCandidate) {
    feedbackInitialized = true;
    feedbackCandidate = feedbackRaw;
    feedbackCandidateSince = now;
  }
  if (static_cast<uint32_t>(now - feedbackCandidateSince) >= FEEDBACK_SETTLE_MS &&
      (!feedbackHasSettled || feedbackSettled != feedbackCandidate)) {
    if (feedbackHasSettled) {
      ++feedbackChanges;
    }
    feedbackSettled = feedbackCandidate;
    feedbackHasSettled = true;
  }
  // Nonblocking diagnostics. Do not assign vehicle-state meanings to these LEDs.
  digitalWrite(Hardware::INDICATOR_D4_PIN, (feedbackRaw & 2U) ? HIGH : LOW);
  digitalWrite(Hardware::INDICATOR_D5_PIN, (feedbackRaw & 1U) ? HIGH : LOW);
  digitalWrite(Hardware::INDICATOR_D6_PIN, feedbackIsStable(now) ? LOW : HIGH);
}

void printFeedbackFields() {
  serviceFeedback();
  Serial.print(F(" FB_D2="));
  Serial.print((feedbackRaw & 2U) ? 1 : 0);
  Serial.print(F(" FB_D3="));
  Serial.print((feedbackRaw & 1U) ? 1 : 0);
  Serial.print(F(" FB_PAIR="));
  if (feedbackHasSettled) {
    Serial.print((feedbackSettled & 2U) ? 1 : 0);
    Serial.print((feedbackSettled & 1U) ? 1 : 0);
  } else {
    Serial.print(F("UNSET"));
  }
  Serial.print(F(" FB_STABLE="));
  const bool stable = feedbackIsStable(millis());
  Serial.print(stable ? F("YES") : F("NO"));
  Serial.print(F(" FB_CHANGES="));
  Serial.print(feedbackChanges);
}

void printStatus() {
  Serial.print(F("STATUS CP_MODE="));
  Serial.print(modeName());
  Serial.print(F(" CP_POSITIVE_DUTY="));
  printDuty(cpDutyTenthPercent);
  Serial.print(F("% D9_LOGIC_HIGH="));
  printDuty(static_cast<uint16_t>(1000U - cpDutyTenthPercent));
  Serial.print(F("% FAULT="));
  Serial.print(faultLatched ? F("YES") : F("NO"));
  Serial.print(F(" REASON="));
  Serial.print(faultReason);
  Serial.print(F(" CONTACTORS=OFF REMOTE="));
  Serial.print(remoteSupervision ? F("ON") : F("OFF"));
  printFeedbackFields();
  Serial.println();
}

void printHelp() {
  Serial.println(F("Commands: HELP, STATUS, A, HLC, PWM <5.0|10.0..96.0>,"));
  Serial.println(F("SESSION START, SESSION STOP, DISABLE, FAULT <text>, RESET,"));
  Serial.println(F("REMOTE ON, REMOTE OFF, HB, PING <text>"));
}

bool parseDutyTenthPercent(const char *text, uint16_t &result) {
  if (text == nullptr || *text == '\0') {
    return false;
  }

  // Parse directly as tenths of a percent instead of using strtof().
  // Some older Arduino AVR toolchains do not expose strtof(), and a fixed-
  // point value is sufficient for the 0.1 % resolution used by this sketch.
  while (*text == ' ') {
    ++text;
  }

  if (!isdigit(static_cast<unsigned char>(*text))) {
    return false;
  }

  uint16_t wholePercent = 0;
  while (isdigit(static_cast<unsigned char>(*text))) {
    wholePercent = static_cast<uint16_t>(wholePercent * 10U +
                                         static_cast<uint16_t>(*text - '0'));
    if (wholePercent > 100U) {
      return false;
    }
    ++text;
  }

  uint8_t tenthPercent = 0;
  if (*text == '.') {
    ++text;
    if (!isdigit(static_cast<unsigned char>(*text))) {
      return false;
    }

    tenthPercent = static_cast<uint8_t>(*text - '0');
    ++text;

    // Accept harmless extra zeroes (for example, 5.00), but reject values
    // requiring finer resolution (for example, 5.05).
    while (isdigit(static_cast<unsigned char>(*text))) {
      if (*text != '0') {
        return false;
      }
      ++text;
    }
  }

  while (*text == ' ') {
    ++text;
  }
  if (*text != '\0' || (wholePercent == 100U && tenthPercent != 0U)) {
    return false;
  }

  result = static_cast<uint16_t>(wholePercent * 10U + tenthPercent);
  return true;
}

void uppercaseCommand(char *text) {
  for (; *text != '\0'; ++text) {
    *text = static_cast<char>(toupper(static_cast<unsigned char>(*text)));
  }
}

void processCommand(char *line) {
  while (*line == ' ') {
    ++line;
  }
  if (*line == '\0') {
    return;
  }

  uppercaseCommand(line);
  lastHeartbeatMs = millis();

  char *argument = strchr(line, ' ');
  if (argument != nullptr) {
    *argument++ = '\0';
    while (*argument == ' ') {
      ++argument;
    }
  }

  // Diagnostic commands remain available while a fault is latched.
  if (strcmp(line, "PING") == 0) {
    Serial.print(F("ACK PING"));
    if (argument != nullptr && *argument != '\0') {
      Serial.print(' ');
      Serial.print(argument);
    }
    Serial.println();
    return;
  }
  if (strcmp(line, "HELP") == 0) {
    printHelp();
    return;
  }
  if (strcmp(line, "STATUS") == 0) {
    printStatus();
    return;
  }
  if (strcmp(line, "RESET") == 0) {
    clearFault();
    return;
  }
  if (strcmp(line, "FAULT") == 0) {
    latchFault(argument);
    return;
  }

  if (faultLatched) {
    Serial.println(F("ERR FAULT_LATCHED; use STATUS or RESET"));
    return;
  }

  if (strcmp(line, "A") == 0) {
    commandSteadyPositive();
    Serial.println(F("ACK A; eventual CP=+12V DC; D9=LOW"));
    return;
  }

  if (strcmp(line, "HLC") == 0) {
    commandCpPwm(50);
    Serial.println(F("ACK HLC; CP=1kHz/5.0%; D9=95.0% HIGH (inverted)"));
    return;
  }

  if (strcmp(line, "PWM") == 0) {
    uint16_t requestedDuty = 0;
    if (!parseDutyTenthPercent(argument, requestedDuty)) {
      Serial.println(F("ERR PWM syntax: PWM <5.0|10.0..96.0>"));
      return;
    }
    if (!dutyIsAllowed(requestedDuty)) {
      Serial.println(F("ERR PWM allowed: 5.0 or 10.0..96.0 percent CP duty"));
      return;
    }
    commandCpPwm(requestedDuty);
    Serial.print(F("ACK PWM CP_DUTY="));
    printDuty(requestedDuty);
    Serial.print(F("% D9_HIGH="));
    printDuty(static_cast<uint16_t>(1000U - requestedDuty));
    Serial.println('%');
    return;
  }

  if (strcmp(line, "SESSION") == 0) {
    if (argument != nullptr && strcmp(argument, "START") == 0) {
      commandCpPwm(50);
      Serial.println(F("ACK SESSION START; HLC 5.0%; CONTACTORS=OFF"));
      return;
    }
    if (argument != nullptr && strcmp(argument, "STOP") == 0) {
      commandSteadyPositive();
      remoteSupervision = false;
      Serial.println(F("ACK SESSION STOP; CP=A; CONTACTORS=OFF; REMOTE=OFF"));
      return;
    }
    Serial.println(F("ERR SESSION syntax: SESSION START|STOP"));
    return;
  }

  if (strcmp(line, "DISABLE") == 0) {
    commandSteadyNegative(false);
    remoteSupervision = false;
    Serial.println(F("ACK DISABLE; eventual CP=-12V DC; D9=HIGH"));
    return;
  }

  if (strcmp(line, "REMOTE") == 0) {
    if (argument != nullptr && strcmp(argument, "ON") == 0) {
      remoteSupervision = true;
      lastHeartbeatMs = millis();
      Serial.println(F("ACK REMOTE ON; heartbeat timeout=3000ms"));
      return;
    }
    if (argument != nullptr && strcmp(argument, "OFF") == 0) {
      remoteSupervision = false;
      Serial.println(F("ACK REMOTE OFF"));
      return;
    }
    Serial.println(F("ERR REMOTE syntax: REMOTE ON|OFF"));
    return;
  }

  if (strcmp(line, "HB") == 0) {
    lastHeartbeatMs = millis();
    Serial.println(F("ACK HB"));
    return;
  }

  Serial.println(F("ERR UNKNOWN_COMMAND; use HELP"));
}

void serviceSerial() {
  while (Serial.available() > 0) {
    const char incoming = static_cast<char>(Serial.read());

    if (incoming == '\r') {
      continue;
    }

    if (incoming == '\n') {
      commandBuffer[commandLength] = '\0';
      processCommand(commandBuffer);
      commandLength = 0;
      continue;
    }

    if (commandLength < sizeof(commandBuffer) - 1U) {
      commandBuffer[commandLength++] = incoming;
    } else {
      commandLength = 0;
      Serial.println(F("ERR COMMAND_TOO_LONG"));
    }
  }
}

void serviceHeartbeat() {
  if (!remoteSupervision || faultLatched) {
    return;
  }

  if (static_cast<uint32_t>(millis() - lastHeartbeatMs) >
      Timing::HEARTBEAT_TIMEOUT_MS) {
    remoteSupervision = false;
    latchFault("HEARTBEAT_TIMEOUT");
  }
}

void setup() {
  // Establish hardware-safe outputs before starting communication.
  pinMode(Hardware::CP_PWM_PIN, OUTPUT);
  pinMode(Hardware::INDICATOR_D4_PIN, OUTPUT);
  pinMode(Hardware::INDICATOR_D5_PIN, OUTPUT);
  pinMode(Hardware::INDICATOR_D6_PIN, OUTPUT);
  pinMode(Hardware::FEEDBACK_D2_PIN, INPUT);
  pinMode(Hardware::FEEDBACK_D3_PIN, INPUT);
  holdIndicatorsOff();
  serviceFeedback();
  commandSteadyPositive();

  Serial.begin(115200);
  delay(50);
  Serial.println(F("EVSE CP controller ready"));
  Serial.println(F("Startup: CP=A (+12V command), D9=LOW, CONTACTORS=OFF"));
  Serial.println(F("Bench feedback monitor: Q3 D2/D3; Pi owns K1/K2; no automatic EV interlocks"));
  Serial.println(F("LED diagnostics v1: D4=raw D2 HIGH; D5=raw D3 HIGH; D6=unsettled"));
  printHelp();
  printStatus();
}

void loop() {
  serviceFeedback();
  serviceSerial();
  serviceHeartbeat();
}

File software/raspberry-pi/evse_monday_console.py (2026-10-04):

#!/usr/bin/env python3
"""Fail-safe CP console and state publisher for Monday's real-EV test.

This is a separate version of evse_bench_console.py.  It remains the only
owner of /dev/ttyUSB0 and GPIO17/GPIO27, polls Arduino STATUS every second,
publishes a fresh atomic snapshot to /run/evse-monday/state.json, and accepts
only a STOP request from the Josev container.

The STOP request is latched: after Josev reaches a forbidden energy-transfer
boundary, A/HLC/PWM are blocked until the operator types RESET.  This program
does not verify physical contacts, isolation, HV, PP wiring or an IMD.
"""

import argparse
import fcntl
import importlib.util
import json
import math
import os
from pathlib import Path
import queue
import re
import signal
import subprocess
import sys
import tempfile
import threading
import time

# SSH_INPUT_UTF8_GUARD
# Replace a malformed SSH-terminal byte instead of terminating the console.
if hasattr(sys.stdin, "reconfigure"):
    sys.stdin.reconfigure(encoding="utf-8", errors="replace")


VERSION = "4-monday-confirm1"
_decoder_path = (Path(__file__).resolve().parent / "iso15118-real-ev/iso15118"
                 / "secc/controller/monday_state.py")
_decoder_spec = importlib.util.spec_from_file_location("monday_console_decoder", _decoder_path)
_decoder = importlib.util.module_from_spec(_decoder_spec)
sys.modules[_decoder_spec.name] = _decoder
_decoder_spec.loader.exec_module(_decoder)
if getattr(_decoder, "OPERATOR_CONFIRMATION_VERSION", None) != 1:
    raise RuntimeError("Console/decoder confirmation versions differ; run installer again")
RUNTIME_DIR = Path("/run/evse-monday")
STATE_PATH = RUNTIME_DIR / "state.json"
COMMAND_PATH = RUNTIME_DIR / "command.json"
LOCK_PATH = "/run/lock/evse_bench_console.lock"

HELP = """Commands (case-insensitive):
  A                  positive DC; K1/K2 ON
  HLC                1 kHz, 5% positive duty; K1/K2 ON
  PWM <duty>         5.0 or 10.0..96.0; K1/K2 ON (bench diagnostics only)
  STOP               K1/K2 OFF, upstream A, REMOTE OFF
  STATUS             Arduino state and Pi relay-command state
  CONFIRM C          scope-observed C2 for 60 s; requires stable HLC pair 11
  CONFIRM AUTO       clear scope confirmation; use automatic mapping
  REMOTE ON / OFF    Arduino heartbeat supervision; no relay change
  HB / PING <text>   communication diagnostics; no relay change
  SESSION START      same as HLC
  SESSION STOP       same as STOP
  DISABLE            K1/K2 OFF, upstream negative DC, REMOTE OFF
  FAULT <text>       K1/K2 OFF and latch an Arduino fault
  RESET              K1/K2 OFF; clear Arduino fault and Josev STOP latch
  EXIT / QUIT        STOP and return to the Pi shell
  HELP               show this list

Monday rule: after an external Josev STOP, use RESET before A or HLC.
A connects the positive DC signal. Use STOP to disconnect it.
CONFIRM C is a human observation, not automatic detection or power permission.
Observe CP positive plateau (not the PWM mean). Clear on return to B.
"""


def atomic_json(path, value):
    path.parent.mkdir(mode=0o770, parents=True, exist_ok=True)
    fd, temporary_name = tempfile.mkstemp(
        prefix=path.name + ".", suffix=".tmp", dir=str(path.parent)
    )
    try:
        with os.fdopen(fd, "w", encoding="utf-8") as stream:
            json.dump(value, stream, sort_keys=True)
            stream.write("\n")
            stream.flush()
            os.fsync(stream.fileno())
        os.chmod(temporary_name, 0o660)
        os.replace(temporary_name, path)
    except Exception:
        try:
            os.unlink(temporary_name)
        except FileNotFoundError:
            pass
        raise


def parse_percent(value):
    try:
        result = float(value.removesuffix("%"))
    except (AttributeError, TypeError, ValueError):
        return None
    return result if math.isfinite(result) else None


def parse_pwm(command):
    match = re.fullmatch(r"PWM +([0-9]{1,3})(?:\.([0-9]+))?", command)
    if not match:
        raise ValueError("Use PWM 5.0 or PWM 10.0..96.0")
    fraction = match[2] or "0"
    if any(char != "0" for char in fraction[1:]):
        raise ValueError("PWM resolution is 0.1%; extra decimal places must be zero")
    tenths = int(match[1]) * 10 + int(fraction[0])
    if tenths != 50 and not 100 <= tenths <= 960:
        raise ValueError("Allowed PWM: 5.0 or 10.0..96.0 percent")
    return tenths


def gpio(on):
    subprocess.run(
        ["pinctrl", "set", "17,27", "op", "dh" if on else "dl"],
        check=True,
        timeout=2,
    )


def fields(line):
    if not line.startswith("STATUS "):
        raise RuntimeError("Expected an Arduino STATUS response")
    return dict(word.split("=", 1) for word in line.split()[1:] if "=" in word)


def check_status(line, expected=None, remote=None, allow_fault=False):
    state = fields(line)
    required = (
        "CP_MODE",
        "CP_POSITIVE_DUTY",
        "D9_LOGIC_HIGH",
        "FAULT",
        "REMOTE",
        "FB_D2",
        "FB_D3",
        "FB_PAIR",
        "FB_STABLE",
        "FB_CHANGES",
    )
    missing = [name for name in required if name not in state]
    if missing:
        raise RuntimeError("Incomplete Arduino STATUS (%s): %s" % (missing, line))
    if state["FAULT"] not in ("NO", "YES") or state["REMOTE"] not in ("OFF", "ON"):
        raise RuntimeError("Incomplete Arduino fault/remote status: " + line)
    if state["FB_D2"] not in ("0", "1") or state["FB_D3"] not in ("0", "1"):
        raise RuntimeError("Invalid comparator feedback: " + line)
    if state["FB_PAIR"] not in ("00", "01", "10", "11"):
        raise RuntimeError("Invalid feedback pair: " + line)
    if state["FB_STABLE"] not in ("YES", "NO"):
        raise RuntimeError("Invalid feedback stability: " + line)
    if state["FAULT"] != "NO" and not allow_fault:
        raise RuntimeError("Arduino reports a fault: " + line)
    if remote is not None and state["REMOTE"] != ("ON" if remote else "OFF"):
        raise RuntimeError("Arduino remote-supervision state changed: " + line)
    if expected:
        mode, duty, logic = expected
        positive = parse_percent(state["CP_POSITIVE_DUTY"])
        high = parse_percent(state["D9_LOGIC_HIGH"])
        if (
            state["CP_MODE"] != mode
            or positive is None
            or high is None
            or abs(positive - duty) > 0.01
            or abs(high - logic) > 0.01
        ):
            raise RuntimeError("Arduino output status changed/mismatched: " + line)
    return state
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

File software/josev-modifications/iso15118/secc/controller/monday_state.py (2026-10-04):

"""Fail-safe decoder for the Monday communication-only EV test.

The host bench console publishes validated Arduino STATUS fields as JSON.
This module deliberately has no Josev imports so its mapping and freshness
rules can be unit-tested independently.
"""

from dataclasses import dataclass
import math
import time
from typing import Any, Mapping, Optional


MAX_STATE_AGE_MS = 2500
OPERATOR_CONFIRMATION_VERSION = 1
CONFIRM_C_TTL_MS = 60_000
CP_MAPPING_PROFILE = "MEASURED_PWM_B10_C11"


@dataclass(frozen=True)
class DecodedCPState:
    cp_state: str
    usable: bool
    reason: str


def _number(value: Any) -> Optional[float]:
    try:
        result = float(value)
    except (TypeError, ValueError):
        return None
    return result if math.isfinite(result) else None


def _operator_c(snapshot, now_unix_ms):
    """Validate a short-lived human observation without modifying raw feedback."""
    observed = snapshot.get("operator_confirmation")
    if not isinstance(observed, Mapping):
        return DecodedCPState("UNKNOWN", False, "Invalid operator confirmation")
    issued = _number(observed.get("issued_unix_ms"))
    expires = _number(observed.get("expires_unix_ms"))
    changes = snapshot.get("fb_changes")
    pid = snapshot.get("pid")
    if (
        observed.get("source") != "PICOSCOPE_OPERATOR"
        or observed.get("state") != "C2"
        or snapshot.get("cp_mode") != "PWM"
        or _number(snapshot.get("cp_positive_duty")) is None
        or abs(float(snapshot["cp_positive_duty"]) - 5.0) > 0.01
        or _number(snapshot.get("d9_logic_high")) is None
        or abs(float(snapshot["d9_logic_high"]) - 95.0) > 0.01
        or snapshot.get("external_stop_latched") is not False
        or snapshot.get("fb_pair") != "11"
        or observed.get("fb_pair") != "11"
        or type(changes) is not int or changes < 0
        or type(observed.get("fb_changes")) is not int
        or observed.get("fb_changes") != changes
        or type(pid) is not int or pid <= 0
        or type(observed.get("console_pid")) is not int
        or observed.get("console_pid") != pid
        or issued is None or expires is None
        or not 0 < expires - issued <= CONFIRM_C_TTL_MS
        or not issued <= now_unix_ms < expires
    ):
        return DecodedCPState("UNKNOWN", False,
                              "Operator C confirmation expired or conditions changed")
    return DecodedCPState(
        "C2", True,
        "OPERATOR CONFIRMED C2 from PicoScope; raw pair=11; %d s remaining"
        % math.ceil((expires - now_unix_ms) / 1000),
    )


def decode_snapshot(
    snapshot: Mapping[str, Any],
    *,
    now_unix_ms: Optional[int] = None,
    max_age_ms: int = MAX_STATE_AGE_MS,
) -> DecodedCPState:
    """Decode a console snapshot without inventing unverified CP states.

    The mapping below is specific to the PCB/Arduino combination physically
    checked by Shri.  A pair is accepted only when the console is running,
    feedback is stable, the Arduino is fault-free, and the snapshot is fresh.
    """

    if not isinstance(snapshot, Mapping):
        return DecodedCPState("UNKNOWN", False, "Snapshot is not an object")
    if snapshot.get("schema") != 1:
        return DecodedCPState("UNKNOWN", False, "Unsupported snapshot schema")
    if snapshot.get("running") is not True:
        return DecodedCPState("UNKNOWN", False, "Bench console is not running")

    updated_ms = _number(snapshot.get("updated_unix_ms"))
    if updated_ms is None:
        return DecodedCPState("UNKNOWN", False, "Missing snapshot timestamp")
    if now_unix_ms is None:
        now_unix_ms = time.time_ns() // 1_000_000
    age_ms = now_unix_ms - updated_ms
    if age_ms < -1000 or age_ms > max_age_ms:
        return DecodedCPState("UNKNOWN", False, "Feedback is stale or future-dated")

    if snapshot.get("fault") != "NO":
        return DecodedCPState("UNKNOWN", False, "Arduino fault is active or unknown")
    if snapshot.get("fb_stable") != "YES":
        return DecodedCPState("UNKNOWN", False, "Comparator feedback is unsettled")

    d2 = snapshot.get("fb_d2")
    d3 = snapshot.get("fb_d3")
    pair = snapshot.get("fb_pair")
    if d2 not in (0, 1) or d3 not in (0, 1):
        return DecodedCPState("UNKNOWN", False, "Invalid comparator bits")
    if pair != f"{d2}{d3}":
        return DecodedCPState("UNKNOWN", False, "Comparator bits and pair disagree")

    relay_command = snapshot.get("relay_command")
    if relay_command == "OFF":
        return DecodedCPState("A1", True, "CP path relays are commanded open")
    if relay_command != "ON":
        return DecodedCPState("UNKNOWN", False, "Relay command is unknown")
    if snapshot.get("external_stop_latched") is True:
        return DecodedCPState("UNKNOWN", False, "Josev STOP is latched")
    if snapshot.get("remote") != "ON":
        return DecodedCPState("UNKNOWN", False, "Arduino heartbeat supervision is off")

    mode = snapshot.get("cp_mode")
    duty = _number(snapshot.get("cp_positive_duty"))

    if snapshot.get("cp_mapping_profile", CP_MAPPING_PROFILE) != CP_MAPPING_PROFILE:
        return DecodedCPState("UNKNOWN", False, "Console/decoder mapping profiles differ")
    if snapshot.get("operator_confirmation") is not None:
        return _operator_c(snapshot, now_unix_ms)

    if mode == "A_POSITIVE_DC":
        mapping = {"00": "A1", "10": "B1", "01": "C1"}
        state = mapping.get(pair)
        if state:
            return DecodedCPState(state, True, "Verified positive-DC mapping")
        return DecodedCPState("UNKNOWN", False, "Unverified pair for positive DC")

    if mode == "PWM" and duty is not None and abs(duty - 5.0) <= 0.01:
        if CP_MAPPING_PROFILE == "MEASURED_PWM_B10_C11":
            mapping = {"00": "A2", "10": "B2", "11": "C2"}
            reason = "Bench-observed 5 percent PWM mapping: B=10 C=11"
        else:
            mapping = {"00": "A2", "11": "B2", "01": "C2"}
            reason = "Original 5 percent PWM mapping; pair 11 cannot distinguish B/C"
        state = mapping.get(pair)
        if state:
            return DecodedCPState(state, True, reason)
        return DecodedCPState("UNKNOWN", False, "Unverified pair for 5 percent PWM")

    return DecodedCPState("UNKNOWN", False, "Output is not A or 5 percent HLC PWM")

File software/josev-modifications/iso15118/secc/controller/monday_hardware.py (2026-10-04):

"""Fail-safe EVSE controller for Shri's communication-only real-EV test.

This controller intentionally reuses Josev's simulated protocol data while
replacing every hardware/safety decision that could imply a real DC power
stage.  The host console remains the only process allowed to own the Arduino
serial port and GPIO17/GPIO27.  Communication with that console is through two
small JSON files in /run/evse-monday.

This is not a production EVSE controller.  It has no IMD, no real DC output
contactors and no pre-charge power stage.  Consequently it must never claim
that isolation is valid or that the DC contactors are closed.
"""

import asyncio
import json
import logging
import os
from pathlib import Path
import tempfile
import time
from typing import Any, Dict

from iso15118.secc.controller.simulator import SimEVSEController
from iso15118.secc.controller.monday_state import decode_snapshot
from iso15118.shared.messages.datatypes import (
    DCEVSEChargeParameter,
    DCEVSEStatus,
    DCEVSEStatusCode,
)
from iso15118.shared.messages.datatypes import EVSENotification as EVSENotificationV2
from iso15118.shared.messages.enums import CpState, IsolationLevel


logger = logging.getLogger(__name__)

RUNTIME_DIR = Path(os.environ.get("MONDAY_RUNTIME_DIR", "/run/evse-monday"))
STATE_PATH = RUNTIME_DIR / "state.json"
COMMAND_PATH = RUNTIME_DIR / "command.json"

# Explicit, temporary communication-only test mode. Disabled by default.
PRECHARGE_PROBE_ENABLED = os.environ.get(
    "MONDAY_PRECHARGE_PROBE", "0"
).strip().lower() in {"1", "true", "yes", "on"}


def _read_snapshot() -> Dict[str, Any]:
    """Return the current console snapshot, or an empty fail-safe value."""

    try:
        with STATE_PATH.open("r", encoding="utf-8") as stream:
            value = json.load(stream)
    except (OSError, ValueError, TypeError) as exc:
        logger.warning("Monday feedback unavailable: %s", exc)
        return {}
    if not isinstance(value, dict):
        logger.warning("Monday feedback is not a JSON object")
        return {}
    return value


def _atomic_json(path: Path, value: Dict[str, Any]) -> None:
    """Write a small JSON request without exposing a partial file."""

    path.parent.mkdir(mode=0o770, parents=True, exist_ok=True)
    fd, temporary_name = tempfile.mkstemp(
        prefix=path.name + ".", suffix=".tmp", dir=str(path.parent)
    )
    try:
        with os.fdopen(fd, "w", encoding="utf-8") as stream:
            json.dump(value, stream, sort_keys=True)
            stream.write("\n")
            stream.flush()
            os.fsync(stream.fileno())
        os.chmod(temporary_name, 0o660)
        os.replace(temporary_name, path)
    except Exception:
        try:
            os.unlink(temporary_name)
        except FileNotFoundError:
            pass
        raise
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

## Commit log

2026-10-04 Initial release of GreenPHY EVSE signalling and communication emulator
    [PWM_Schematic.kicad_pcb, PWM_Schematic.kicad_sch, PWM_Schematic_BOM_2026-10-04.csv]
2026-10-05 Add reproducible Raspberry Pi setup and repair installer
